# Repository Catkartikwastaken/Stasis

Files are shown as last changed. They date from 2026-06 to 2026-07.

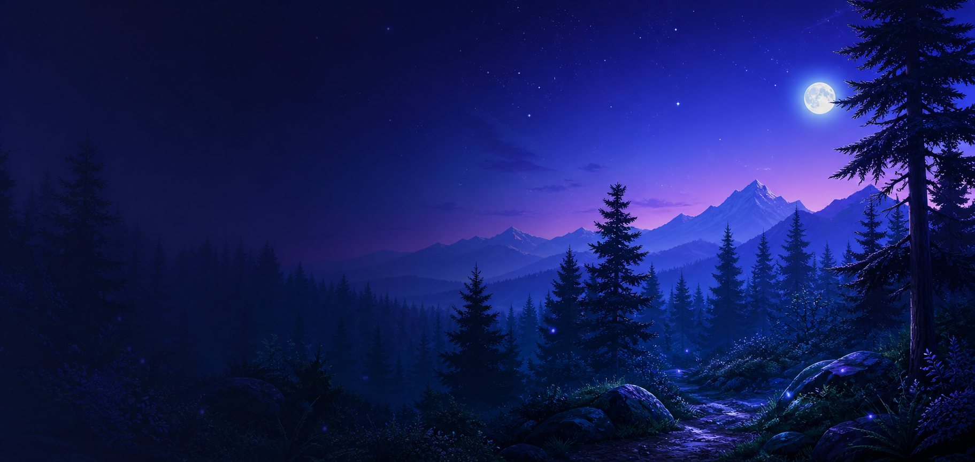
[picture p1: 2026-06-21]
docs/assets/forest-hero.jpg

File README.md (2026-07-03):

# STASIS

**A Raspberry Pi rover platform for forest-style monitoring, live camera streaming, object detection, and dashboard-guided response — built as a competition entry for field robotics and AI-integrated monitoring systems.**

STASIS is a competition-grade prototype for a small monitoring rover designed to showcase real-time edge-AI detection, telemetry-driven situational awareness, and operator-in-the-loop decision making. It is built around a Raspberry Pi 2B, a USB webcam, a Windows laptop for heavier vision processing, and a browser dashboard that shows what the rover sees and how it is responding.

The current build is focused on an indoor forest-like demo space: no GPS, no complicated field infrastructure, and no unnecessary hardware. The rover streams camera frames from the Raspberry Pi, the Windows server analyzes them, and the dashboard turns detections into clear alerts, map points, and simple movement guidance.

> **Competition Project Website:** [catkartikwastaken.github.io/Stasis](https://catkartikwastaken.github.io/Stasis)

## Highlights

| Area | What STASIS Does |
| --- | --- |
| Live rover vision | Streams the Raspberry Pi webcam feed to the dashboard. |
| Human detection | Detects people and surfaces them as high-priority dashboard alerts. |
| Object and marker detection | Supports demo objects, green-strip navigation markers, and empty-background dataset collection. |
| Rover control | Sends manual, scan, stop, return-home, and marker navigation commands from the dashboard to the Pi. |
| Minimal wiring | Keeps the main system centered on the Raspberry Pi, webcam, motor driver path, and optional ESP32-S3 bridge. |
| Extensible AI | Supports local or API-based vision providers, plus custom dataset capture for training a better model. |

## System Flow

The webcam belongs on the Raspberry Pi. The laptop runs the dashboard and the heavier AI work.

```mermaid
flowchart LR
    Camera["USB webcam on Raspberry Pi"] --> Pi["Raspberry Pi rover client"]
    Pi -->|"camera frames + telemetry"| Server["Windows STASIS server"]
    Server -->|"detections + commands"| Pi
    Server --> Dashboard["Browser dashboard"]
    Dashboard -->|"manual controls + tracking"| Server
    Pi --> Motors["L911S motors / optional ESP32-S3 bridge"]
```

In plain English:

1. The Raspberry Pi captures webcam frames.
2. The Pi sends frames to the Windows server through WebSocket.
3. The server runs the selected vision pipeline.
4. The result goes back to the Pi and appears on the dashboard.
5. The dashboard can track a detected target, show map dots, and send rover commands.

## Raspberry Pi Pin Map

Use BCM GPIO numbers in code. All pins are from the Raspberry Pi 2B 40-pin header.

| Function | BCM GPIO | Physical Pin |
| --- | --- | --- |
| Left motor forward | GPIO5 | Pin 29 |
| Left motor reverse | GPIO6 | Pin 31 |
| Right motor forward | GPIO13 | Pin 33 |
| Right motor reverse | GPIO19 | Pin 35 |
| Ultrasonic trigger | GPIO23 | Pin 16 |
| Ultrasonic echo | GPIO24 | Pin 18 |
| Scanner servo signal | GPIO18 | Pin 12 |
| I2C SDA | GPIO2 | Pin 3 |
| I2C SCL | GPIO3 | Pin 5 |
| 3.3V sensor power | 3V3 | Pin 1 or 17 |
| 5V power | 5V | Pin 2 or 4 |
| Ground | GND | Pin 6, 9, 14, 20, 25, 30, 34, or 39 |

## Hardware Connections

### Minimal Demo Wiring (Simplest Working Rover)

| Raspberry Pi | Component |
| --- | --- |
| USB port | USB webcam |
| GPIO5 | L911S A-IA (left motor forward) |
| GPIO6 | L911S A-IB (left motor reverse) |
| GPIO13 | L911S B-IA (right motor forward) |
| GPIO19 | L911S B-IB (right motor reverse) |
| GND | L911S GND |

**Motor power (separate battery):**
- Motor battery positive → L911S VCC / VM
- Motor battery negative → L911S GND (shared with Pi GND)
- L911S Motor A output → Left DC motor
- L911S Motor B output → Right DC motor

### L911S Direct Motor Control

| L911S Pin | Connect To |
| --- | --- |
| A-IA | Pi GPIO5 (pin 29) |
| A-IB | Pi GPIO6 (pin 31) |
| B-IA | Pi GPIO13 (pin 33) |
| B-IB | Pi GPIO19 (pin 35) |
| VCC / VM | Motor battery positive |
| GND | Motor battery negative + Pi GND |
| Motor A output | Left DC motor |
| Motor B output | Right DC motor |

Config: `"direct_motor_control": true`, `"esp32_serial_control": false`

### ESP32-S3 Optional Motor Bridge

Use only if you want serial-delegated motor control. Do NOT connect both Pi GPIO and ESP32 GPIO to the L911S simultaneously.

| Raspberry Pi | ESP32-S3 |
| --- | --- |
| USB port | ESP32-S3 USB/UART port |

| ESP32-S3 GPIO | L911S Pin |
| --- | --- |
| GPIO4 | A-IA |
| GPIO5 | A-IB |
| GPIO6 | B-IA |
| GPIO7 | B-IB |
| GND | L911S GND |

Config: `"direct_motor_control": false`, `"esp32_serial_control": true`, `"esp32_serial_port": "/dev/ttyUSB0"`, `"esp32_baudrate": 115200`

### USB Webcam

| Webcam | Raspberry Pi |
| --- | --- |
| USB cable | Pi USB port |

Verify: `ls /dev/video*`. Config: `"camera": { "enabled": true, "index": 0 }`

### HC-SR04 Ultrasonic Sensor

| HC-SR04 Pin | Connect To |
| --- | --- |
| VCC | 5V |
| GND | Pi GND |
| TRIG | GPIO23 (pin 16) |
| ECHO | GPIO24 (pin 18) **through voltage divider / level shifter (5V → 3.3V)** |

Config: `"ultrasonic_enabled": true`

### SG90 Scanner Servo

| Servo Wire | Connect To |
| --- | --- |
| Signal | GPIO18 (pin 12) |
| VCC | External 5V servo supply (not Pi 5V) |
| GND | External supply GND + Pi GND |

Config: `"scanner_servo_enabled": true`

### MPU6050 IMU (I2C)

| MPU6050 Pin | Connect To |
| --- | --- |
| VCC | 3.3V |
| GND | Pi GND |
| SDA | GPIO2 (pin 3) |
| SCL | GPIO3 (pin 5) |

Config: `"i2c_enabled": true`, `"mpu6050_enabled": true`

### HMC5883L / QMC5883L Compass (I2C)

| Compass Pin | Connect To |
| --- | --- |
| VCC | 3.3V |
| GND | Pi GND |
| SDA | GPIO2 (pin 3) |
| SCL | GPIO3 (pin 5) |

Config: `"i2c_enabled": true`, `"compass_enabled": true`

### Important Power Rules

1. Do **not** power DC motors from Raspberry Pi 5V.
2. Use a separate motor battery for the L911S motor driver.
3. Pi GND, L911S GND, sensor GND, servo GND, and motor battery negative must share common ground.
4. Pi GPIO pins are 3.3V logic. HC-SR04 Echo is 5V — use a voltage divider/level shifter.
5. Do not power a moving servo from Pi 5V if it causes resets.

### Fault-Tolerant Behavior

Missing sensors are logged as warnings and disabled; the rest of the system keeps running. Camera streaming and object detection work even when motors, IMU, compass, or ultrasonic are disconnected.

## What It Detects

STASIS keeps detections focused on the rover mission:

```text
human              people or intruders in the demo area
animal             animal stand-ins or wildlife-style targets
alpha_tester_object custom demo objects for the trained dataset
green_strip          navigation marker strips
empty_background   clean negative examples for model training
fire / track       supported in the broader alert contract
```

For the current demo, normal indoor doors, windows, and random room features should not become target alerts.

## Quick Start

### 1. Start The Windows Server

On the Windows laptop:

```powershell
cd server
py -m venv .venv
.\.venv\Scripts\activate
python -m pip install --upgrade pip
pip install -r requirements-api.txt
copy vision_config.example.json vision_config.json
python security_rover_server_windows.py
```

The server prints an address such as:

```text
http://192.168.29.69:5000
```

Use that IP in the Raspberry Pi config.

### 2. Start The Raspberry Pi Rover

On the Raspberry Pi:

```bash
cd ~/Documents/Stasis/rover/rpi2b
python3 -m venv .venv
. .venv/bin/activate
python -m pip install --upgrade pip
pip install -r requirements.txt
cp config.example.json config.json
nano config.json
```

Set `server_host` to the Windows laptop IP:

```json
{
  "server_host": "192.168.29.69"
}
```

Then run the rover client:

```bash
python rover_client.py --config config.json
```

Use `--simulate` only for network testing. For the real rover, keep simulation off.

### 3. Open The Dashboard

On the laptop browser:

```text
http://<WINDOWS_LAPTOP_IP>:5000
```

You should see the live Pi webcam feed, rover status, controls, alerts, and the tracking map.

## Dataset Capture

STASIS includes a beginner-friendly webcam capture tool for building a custom object dataset:

```powershell
python tools\dataset_capture_assistant.py
```

It captures:

- `alpha_tester_object`
- `green_strip`
- `empty_background`

The tool lets you choose camera resolution, FPS, brightness, contrast, exposure, focus, and save location from the app itself. See [Dataset Capture Assistant](docs/DATASET_CAPTURE_ASSISTANT.md).

## Competition Project Website

The project's competition landing page is live at **[catkartikwastaken.github.io/Stasis](https://catkartikwastaken.github.io/Stasis)**.

The site (built from [docs/index.html](docs/index.html)) covers the system overview, rover pipeline, scroll-driven mission reel, setup instructions, hardware connections, and links to all project documentation — presented as a polished field platform showcase.

## Project Structure

```text
server/
  templates/index.html                    Main dashboard UI
  vision_config.example.json              Vision provider configuration template

rover/rpi2b/
  rover_client.py                         Raspberry Pi rover client
  rover_client_object_detection.py        Pi-side camera streaming and local detection path
  config.example.json                     Pi configuration template
  requirements.txt                        Pi dependencies

tools/
  dataset_capture_assistant.py            Webcam dataset collection app

hardware/cad/stasis-design/
  stasis-redesigns-compartment.zip        Archive containing redesign and compartment CAD assets

docs/
  index.html                              GitHub Pages project website
  README_ROVER_SYSTEM.md                  Full rover setup guide
  VISION_PROVIDERS.md                     Cloud/local AI provider notes
  WINDOWS_YOLO_ONNX_DETECTION.md          Windows ONNX detector guide
  DATASET_CAPTURE_ASSISTANT.md            Dataset tool guide
```

## Documentation

- [Full Rover System Guide](docs/README_ROVER_SYSTEM.md)
- [Wiring And Runbook](docs/WIRING_AND_RUNBOOK.md)
- [Vision Providers](docs/VISION_PROVIDERS.md)
- [Windows YOLO ONNX Detection](docs/WINDOWS_YOLO_ONNX_DETECTION.md)
- [Dataset Capture Assistant](docs/DATASET_CAPTURE_ASSISTANT.md)
- [Project Brief](docs/PROJECT_BRIEF.md)

## Current Limits

STASIS is still a prototype, so the current build is intentionally honest about what it can and cannot do:

- GPS is not used for the indoor demo.
- Distance and map guidance are approximate without wheel encoders.
- Heavy AI should run on the laptop or through an API, not on the Raspberry Pi 2B.
- Custom object detection quality depends heavily on the dataset and trained model.
- Optional sensors should stay disabled until the hardware is physically connected.

## License

This project is intended as an open-source learning and robotics build. Add the final license file before using it in a public release or competition submission.

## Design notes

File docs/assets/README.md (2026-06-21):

# STASIS Pages Assets

Website images:

- `forest-hero.jpg` - original generated forest hero image
- `stasis-forest-real.jpg` - realistic field background for the current home page

The GitHub Pages site at `docs/index.html` is already wired to use these local files.

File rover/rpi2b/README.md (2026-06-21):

# STASIS Raspberry Pi 2B Rover Client

This Python client runs the Raspberry Pi 2B side of the STASIS rover. It connects to the existing STASIS Flask server at `ws://<SERVER_IP>:5000/ws/rover`, registers as `rpi2b_rover`, accepts `goto`, `scan`, and `stop` commands, drives the L911S/L9110S motor driver, reads optional MPU6050 and GY-271/HMC5883L sensors, scans with optional HC-SR04 and servo hardware, and sends telemetry back to the dashboard.

The USB webcam connects to the Raspberry Pi. The Pi captures frames with Python/OpenCV, sends them to the Windows laptop over the rover WebSocket, receives Gemma `vision_result` messages, and sends `vision_decision` back to the server/dashboard.

The default config is intentionally minimal-wire: the Pi drives motors directly, but I2C heading sensors, ultrasonic, and the scanner servo are disabled until you enable them. With no heading sensor, the client uses timed open-loop turns for the indoor demo.

## Raspberry Pi Setup

Use Raspberry Pi OS on the Pi 2B and enable I2C:

```bash
sudo raspi-config
```

Open `Interface Options`, enable `I2C`, then reboot.

Install dependencies:

```bash
cd rover/rpi2b
python3 -m venv .venv
. .venv/bin/activate
python -m pip install --upgrade pip
pip install -r requirements.txt
```

Create a local config:

```bash
cp config.example.json config.json
```

Edit `server_host` to the IP address of the laptop running `server/security_rover_server_windows.py` or `server/security_rover_server.py`.

Keep the webcam section enabled for the real demo:

```json
{
  "camera": {
    "enabled": true,
    "index": 0,
    "width": 640,
    "height": 480,
    "upload_interval_seconds": 2.0
  }
}
```

If the Pi opens the wrong webcam, change `camera.index` to `1` or `2`.

Enable optional hardware and ESP32 serial motor control only when they are physically connected:

```json
{
  "hardware": {
    "direct_motor_control": false,
    "esp32_serial_control": true,
    "esp32_serial_port": "/dev/ttyUSB0",
    "esp32_baudrate": 115200,
    "i2c_enabled": true,
    "mpu6050_enabled": true,
    "compass_enabled": true,
    "ultrasonic_enabled": true,
    "scanner_servo_enabled": true
  }
}
```

Hardware is initialized per subsystem. A missing ultrasonic sensor, scanner servo, MPU6050, compass, or motor driver is logged and disabled without stopping the rest of the Pi client, so camera streaming and object detection can keep running.

Run the rover:

```bash
python rover_client.py --config config.json
```

For a laptop protocol test without GPIO hardware:

```bash
python rover_client.py --server 192.168.1.10 --simulate
```

To run the client automatically on boot, edit `stasis-rover.service.example` so the paths match where this repo lives on your Pi, copy it to `/etc/systemd/system/stasis-rover.service`, then run:

```bash
sudo systemctl daemon-reload
sudo systemctl enable --now stasis-rover
sudo systemctl status stasis-rover
```

## Wiring Diagrams

The rover supports direct GPIO motor control and optional mediated ESP32-S3 control. Direct GPIO can use either `l911s` or `l298n` mode.

The physical rover uses four DC motors. The software still drives it as a differential rover with two side channels: the two left motors receive the same left-side signal, and the two right motors receive the same right-side signal. Wire both left motors to the left motor channel and both right motors to the right motor channel only if your motor driver and battery can safely supply the total current.

### Option A: Direct Raspberry Pi GPIO L911S Control
Uses Raspberry Pi BCM GPIO pin allocations:

```text
BCM 5   -> A-IA / IA, left motor forward input
BCM 6   -> A-IB / IB, left motor reverse input
BCM 13  -> B-IA, right motor forward input
BCM 19  -> B-IB, right motor reverse input
GND     -> L911S/L9110S GND and motor battery negative
VM/VCC  -> Motor battery positive, matched to your motors/driver board
Motor A output -> both left-side DC motors
Motor B output -> both right-side DC motors
```

### Option B: Direct Raspberry Pi GPIO L298N Control
Use this if the L911S channel is damaged or if you want a stronger dual H-bridge module:

```text
BCM 5   -> IN1, left motor forward input
BCM 6   -> IN2, left motor reverse input
BCM 13  -> IN3, right motor forward input
BCM 19  -> IN4, right motor reverse input
BCM 12  -> ENA, left speed enable
BCM 20  -> ENB, right speed enable
GND     -> L298N GND and motor battery negative
+V      -> Motor battery positive, matched to your motors
OUT1/2  -> left-side DC motor or motor pair
OUT3/4  -> right-side DC motor or motor pair
```

Config:

```json
"hardware": {
  "direct_motor_control": true,
  "motor_driver": "l298n"
},
"pins": {
  "left_motor_forward": 5,
  "left_motor_reverse": 6,
  "right_motor_forward": 13,
  "right_motor_reverse": 19,
  "left_motor_enable": 12,
  "right_motor_enable": 20
}
```

Remove the ENA/ENB jumpers for Raspberry Pi speed control. If the jumpers stay installed, set `left_motor_enable` and `right_motor_enable` to `null`.

### Option C: ESP32-S3 Mediated L911S Control
Raspberry Pi communicates with the ESP32-S3 via USB-Serial. The ESP32-S3 drives the H-bridge directly:

**1. USB Link:**
- USB port of the Raspberry Pi 2B connected via USB cable to the ESP32-S3's UART/USB port.

**2. ESP32-S3 to L911S Wiring:**
```text
ESP32 Pin 4 (GPIO4) -> A-IA, left motor forward input
ESP32 Pin 5 (GPIO5) -> A-IB, left motor reverse input
ESP32 Pin 6 (GPIO6) -> B-IA, right motor forward input
ESP32 Pin 7 (GPIO7) -> B-IB, right motor reverse input
GND                 -> L911S GND and motor battery negative
VM/VCC              -> Motor battery positive
Motor A output      -> both left-side DC motors
Motor B output      -> both right-side DC motors
```

---

### Onboard I2C Sensors & Sonar Sweep Peripherals

I2C sensors:

```text
BCM 2 / physical pin 3  -> SDA
BCM 3 / physical pin 5  -> SCL
3V3                     -> MPU6050 VCC and GY-271 VCC
GND                     -> MPU6050 GND and GY-271 GND
MPU6050 address         -> 0x68
GY-271/HMC5883L address -> 0x1E
```

HC-SR04 ultrasonic sensor:

```text
BCM 23 -> Trig
BCM 24 -> Echo
5V or 3V3 -> VCC
GND -> GND
```

Raspberry Pi GPIO is not 5V tolerant. If the HC-SR04 is powered from 5V, put a voltage divider or level shifter on Echo before it reaches BCM 24.

Scanner servo:

```text
BCM 18 -> Signal
5V     -> Servo power
GND    -> Ground
```

Use a common ground between the Pi, motor driver, motor battery, sensors, and servo. Use a separate motor/servo supply where possible because motor noise and voltage dips can reboot the Pi.

## Tuning

Open-loop distance and minimal-wire turning are approximate because the rover has no wheel encoders. Tune these values in `config.json`:

```json
{
  "hardware": {
    "open_loop_turn_degrees_per_second": 90.0
  },
  "motion": {
    "drive_ms_per_cm": 50.0,
    "drive_pwm": 70.0,
    "turn_kp": 0.8,
    "turn_tolerance_deg": 5.0
  }
}
```

If the rover drives too far, lower `drive_ms_per_cm`. If it stops short, raise it. If turning oscillates, lower `turn_kp`; if it turns too slowly, raise `turn_kp` or `turn_min_pwm`.

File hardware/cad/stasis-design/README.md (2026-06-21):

# STASIS CAD Archive

This folder now keeps a single archive:

```text
stasis-redesigns-compartment.zip
```

The zip contains the redesign and compartment CAD assets exported from:

```text
C:\Users\CatKartikSUPREMEPC\Documents\Stasis Design
```

It replaces the extracted file tree so the repo stays compact while still carrying the design package.

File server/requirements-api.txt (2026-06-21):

flask
flask-socketio
simple-websocket
opencv-python
numpy
pillow
requests

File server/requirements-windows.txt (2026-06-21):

flask
flask-socketio
simple-websocket
opencv-python
pillow
requests
torch
torchvision
transformers>=4.53.0
accelerate
sentencepiece
protobuf

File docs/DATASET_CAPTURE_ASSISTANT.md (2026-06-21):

---
title: Dataset Capture Assistant
---

# Dataset Capture Assistant

Use this tool to take training photos with the webcam in a simple manual workflow. It opens a persistent desktop app, shows what kind of scene to capture next, and saves photos without closing the app.

## Install

From the repo root:

```powershell
python -m pip install opencv-python numpy pillow
```

## Start

```powershell
python tools\dataset_capture_assistant.py
```

Pick the class from the dropdown, then follow the on-screen prompts.

You can also start a class directly:

```powershell
python tools\dataset_capture_assistant.py --class-name green_strip
python tools\dataset_capture_assistant.py --class-name alpha_tester_object
python tools\dataset_capture_assistant.py --class-name empty_background
```

Images are saved to:

```text
C:\Users\<you>\Pictures\STASIS_Dataset\raw\<class_name>\
```

Use the `Choose Folder` button if you want another save location.

## Controls

```text
Space/C = capture now
N = next idea
L = next location
R = delete last saved image
Q = quit
```

## Camera Settings

The app lets you change common webcam settings without editing code:

```text
camera index
width
height
FPS
brightness
contrast
exposure
focus
```

The camera/settings sidebar is scrollable. Use the mouse wheel if the lower settings are outside the window.

It also shows:

```text
current resolution
estimated megapixels
camera backend
current property values
```

Most webcams do not report live electrical power usage through normal camera drivers, so the app shows power draw as unavailable when the camera does not expose it.

## Recommended Use

For the current demo dataset, use:

```text
alpha_tester_object
green_strip
empty_background
```

Take roughly 200 total photos across 4 locations. Mix objects together naturally, but still take empty background photos so the model learns when nothing important is present.

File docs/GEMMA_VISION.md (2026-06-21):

---
title: Gemma Vision
---

# Gemma Vision Integration

STASIS uses Gemma on the Windows laptop/server to inspect USB webcam frames captured by the Raspberry Pi. The rover does not run Gemma; the Raspberry Pi 2B captures the webcam, streams frames to Windows, receives `vision_result`, decides the action, and sends `vision_decision` back to the dashboard/server.

Gemma is now one supported local provider, not the only vision option. For Gemini API, OpenAI, Anthropic, Qwen DashScope, Kimi, Zhipu, Ollama, or LM Studio, use `docs/VISION_PROVIDERS.md`.

## Default Model

The server defaults to:

```text
google/gemma-4-E2B-it
```

This is a multimodal Gemma instruct model that supports image + text input through Hugging Face Transformers. The server uses the documented `any-to-any` pipeline and sends a chat-style message containing:

```text
1. The latest Raspberry Pi webcam frame as a PIL image.
2. A strict JSON instruction prompt.
```

The expected model response is:

```json
{"detected": true, "category": "human", "message": "person visible beside the patrol marker"}
```

or:

```json
{"detected": false, "category": "", "message": ""}
```

The server calls the pipeline with `return_full_text=False` and deterministic generation settings so the parser sees only Gemma's new answer, not the original prompt.

## Hugging Face Access

Gemma 4 model weights are hosted on Hugging Face. If your environment needs authentication for downloads or you hit rate limits, create a Hugging Face access token.

Set the token before starting the server.

PowerShell:

```powershell
$env:HF_TOKEN = "hf_your_token_here"
```

Bash:

```bash
export HF_TOKEN="hf_your_token_here"
```

You can also run `huggingface-cli login` on the server machine.

## Install

Install the normal server requirements. They include the Transformers version needed for Gemma any-to-any inference.

Windows PowerShell:

```powershell
cd server
py -m venv .venv
.\.venv\Scripts\activate
python -m pip install --upgrade pip
pip install -r requirements-windows.txt
```

Linux:

```bash
cd server
python3 -m venv .venv
. .venv/bin/activate
python -m pip install --upgrade pip
pip install -r requirements.txt
```

If you are using only API providers, Ollama, or LM Studio, install `requirements-api.txt` instead. That lighter install does not require Torch.

## Configuration

For local Gemma, copy `server/vision_config.example.json` to `server/vision_config.json`, enable `local_gemma`, and put it in `provider_order`. The legacy environment variables below still work for Gemma tuning when needed:

```text
STASIS_VISION_ENABLED=true
STASIS_VISION_REQUIRED=false
STASIS_VISION_MODEL=google/gemma-4-E2B-it
STASIS_VISION_PIPELINE_TASK=any-to-any
STASIS_VISION_DEVICE=auto
STASIS_VISION_DEVICE_MAP=none
STASIS_VISION_TORCH_DTYPE=auto
STASIS_VISION_MAX_NEW_TOKENS=160
STASIS_ANALYSIS_INTERVAL_SECONDS=2
STASIS_CAMERA_SOURCE=rover
STASIS_CAMERA_INDEX=0
STASIS_CAMERA_WIDTH=640
STASIS_CAMERA_HEIGHT=480
STASIS_CAMERA_FPS=15
STASIS_CAMERA_BACKEND=dshow
```

Recommended Windows CUDA settings:

```powershell
$env:STASIS_VISION_DEVICE = "cuda"
$env:STASIS_VISION_DEVICE_MAP = "none"
$env:STASIS_VISION_TORCH_DTYPE = "bfloat16"
$env:STASIS_VISION_REQUIRED = "true"
python security_rover_server_windows.py
```

CPU fallback:

```powershell
$env:STASIS_VISION_DEVICE = "cpu"
$env:STASIS_VISION_DEVICE_MAP = "none"
$env:STASIS_VISION_TORCH_DTYPE = "float32"
python security_rover_server_windows.py
```

CPU inference can be slow. If you only want to test rover control and the dashboard, disable vision:

```powershell
$env:STASIS_VISION_ENABLED = "false"
python security_rover_server_windows.py
```

## Prompt Contract

The server prompt asks Gemma to return only one JSON object:

```json
{"detected": boolean, "category": "human|animal|track|fire|marker", "message": string}
```

The parser accepts plain JSON or the first valid JSON object embedded in extra model text. If `detected` is false, the server clears `message` before broadcasting. If the category is missing or outside the STASIS categories, the alert is suppressed. If the response cannot be parsed, the error is logged and no alert is emitted for that frame.

The default categories for the forest-monitoring demo are:

```text
human   -> humans, intruders, people in the test area
animal  -> animals or wildlife stand-ins
track   -> footprints, trails, soil changes, disturbed ground, track marks
fire    -> flame, smoke, fire-like hazards
marker  -> custom navigation markers such as green strips
```

The demo is indoors, but the prompt treats the scene as a staged forest floor. It intentionally avoids alerting on ordinary doors or windows unless they matter to the demo setup.

To customize the prompt:

PowerShell:

```powershell
$env:STASIS_ANALYSIS_PROMPT = "Analyze this STASIS forest-monitoring rover frame for humans, animals, tracks, fire, or red navigation strips. Return only JSON with detected and message."
```

Keep the same JSON schema so the dashboard and category filter continue to work.

## Troubleshooting

If model loading fails with an authorization error:

```text
1. Set HF_TOKEN or run huggingface-cli login.
2. Restart the server.
```

If model loading fails because of Transformers support:

```bash
pip install --upgrade "transformers>=4.53.0" torch torchvision accelerate sentencepiece protobuf
```

If CUDA runs out of memory:

```text
1. Lower STASIS_CAMERA_WIDTH and STASIS_CAMERA_HEIGHT.
2. Increase STASIS_ANALYSIS_INTERVAL_SECONDS.
3. Try STASIS_VISION_TORCH_DTYPE=bfloat16.
4. Disable vision while testing rover control.
```

If the wrong webcam opens on the Raspberry Pi, change `camera.index` in `rover/rpi2b/config.json`, then restart the Pi rover client. If you intentionally test with a laptop webcam, set `STASIS_CAMERA_SOURCE=local` on Windows and then use `STASIS_CAMERA_INDEX`.

If alerts are noisy, adjust `STASIS_ANALYSIS_PROMPT` to describe only the objects or events that matter for your test space.

## References

- Hugging Face model page: https://huggingface.co/google/gemma-4-E2B-it
- Google Gemma documentation: https://ai.google.dev/gemma

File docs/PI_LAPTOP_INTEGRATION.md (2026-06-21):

# STASIS Pi ↔ Laptop Integration (Stable Path)

This mode runs object detection on the **Windows laptop** while the **Pi only streams camera + telemetry**.

## 1) Windows laptop (server + detector)

From PowerShell:

```powershell
cd C:\Users\Car\Documents\Stasis\server
python -m pip install -r requirements-object-detection.txt

$env:STASIS_DETECTION_AUTHORITY="windows"
$env:STASIS_WINDOWS_DETECTOR_RUNTIME="ultralytics"
$env:STASIS_ULTRALYTICS_MODEL="yoloe-26s-seg.pt"
$env:STASIS_ULTRALYTICS_DEVICE="cuda:0"
$env:STASIS_REQUIRE_CUDA="false"
$env:STASIS_OBJECT_ANALYSIS_INTERVAL_SECONDS="0.2"

python security_rover_server_object_detection.py
```

Notes:
- If CUDA is unavailable and `STASIS_REQUIRE_CUDA=false`, server falls back to CPU.
- Dashboard URL: `http://127.0.0.1:5000`

## 2) Raspberry Pi (stream camera + rover control)

Use the profile `rover/rpi2b/profiles/laptop_detection_pi_stream.json`.

- This profile is stream-only (no Pi-side detector block).
- Set `server_host` in the profile to your laptop IP, or override via env:
  `export STASIS_SERVER_HOST=<LAPTOP_IP>`

Then run:

```bash
cd ~/Documents/Stasis/rover/rpi2b
source .venv/bin/activate
python rover_client.py --config profiles/laptop_detection_pi_stream.json
```

## 3) Validation checklist

- Pi logs show successful WebSocket handshake/registration.
- Laptop logs show: `Windows-side detection active with 1 detector(s).`
- Laptop logs show repeated detection debug entries after Pi frames arrive.
- Dashboard (`/`) shows live camera feed and detection overlays/debug rows.

## 4) Troubleshooting

- If camera feed is blank: verify Pi `server_host`, websocket path `/ws/rover`, and webcam index on Pi.
- If detections are missing: set `STASIS_ULTRALYTICS_MODEL="yolo11n.pt"` to sanity-check baseline detection.
- If too slow: lower `STASIS_ULTRALYTICS_IMGSZ` (for example `512`).

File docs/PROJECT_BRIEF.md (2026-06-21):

---
title: Project Brief
---

# STASIS Project Brief

STASIS is a forest monitoring rover. The first demo will happen indoors in a forest-like test space, so the system should behave like a patrol robot without depending on GPS.

## Current Mission

The rover should patrol a test area, watch the camera feed, and notify the dashboard when the selected multimodal model sees something important.

Primary detection targets:

```text
Humans/intruders
Animals or wildlife stand-ins
Soil changes, tracks, footprints, trails, or disturbed ground
Fire, smoke, or flame-like hazards
Custom colored markers or strips, especially green strips
```

Intruders are classified under the `human` category. Ordinary indoor doors and windows are not target classes for this project.

## Demo Hardware Plan

Current hardware assumptions:

```text
Laptop              -> Flask/Socket.IO server, dashboard, multimodal AI provider
USB webcam          -> Camera input captured by Raspberry Pi Python/OpenCV
Raspberry Pi 2B     -> High-level rover client, camera streaming, logic, state, and telemetry
ESP32-S3 (Optional) -> Low-level serial motor driver (serial control mode)
L911S motor driver  -> A-IA/A-IB and B-IA/B-IB motor inputs (driven by ESP32 or direct Pi)
Sensors             -> Obstacle avoidance, heading, scan, and demo telemetry
```

The old embedded camera path has been completely removed. The Raspberry Pi now captures the USB webcam, streams JPEG frames to the Windows laptop for multimodal AI processing, receives the vision result, and decides whether to stop, alert, remember a marker, or continue. The dashboard camera feed is served from the latest Pi frame at `/camera.mjpg`. The ESP32-S3 code is dedicated strictly to low-level motor driver controls, serving as a serial-to-PWM bridge for the L911S to ensure stable and highly precise timing.

The current code supports two motor driver topologies: Option A (Direct Raspberry Pi BCM GPIO control) and Option B (ESP32-S3 USB/UART serial delegated control). The default configuration can be run in minimal-wire direct mode or serial-delegated mode; optional I2C heading sensors, ultrasonic, and servo scanning are disabled by default until explicitly enabled in the configuration file.

## Behavior Targets

STASIS should support:

```text
Autonomous patrol scripts
Manual dashboard controls
Clicked map goals
Return-to-home
Obstacle avoidance
Human/intruder alerts
Animal alerts
Track and soil-change alerts
Fire alerts
Custom marker search and marker-directed patrol
```

For the green-strip demo, the rover should be able to scan for a requested strip, remember where it was found, and later drive back to that strip when commanded.

The Pi now receives vision results before an alert is shown. For humans and fire it stops and approves an alert; for markers it approves the marker memory path so the dashboard can request a green-strip search and command the rover back to the last seen strip.

## Open Decisions

These details should be confirmed before the next hardware-specific implementation pass:

```text
Exact sensor list and which board each sensor connects to
Marker colors, marker names, and what action each marker should trigger
Indoor demo arena size and expected patrol route shape
```

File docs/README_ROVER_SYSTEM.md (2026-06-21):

---
title: Rover System
---

# STASIS Forest Monitoring Rover System

## Plain-English Overview

STASIS has two main computers:

```text
Raspberry Pi 2B  -> sits on the rover, uses the webcam, controls movement
Windows laptop   -> runs the dashboard and selected multimodal vision provider
```

The Raspberry Pi is the rover brain. It captures webcam frames, sends them to the Windows laptop, receives the AI vision result, and decides what the rover should do next.

The Windows laptop is the AI and dashboard station. It calls the configured multimodal provider, serves the web dashboard, and passes commands between the dashboard and the Pi.

The webcam should be connected to the Raspberry Pi for the real demo. The laptop webcam mode exists only for quick testing.

This repository contains a complete starter setup for STASIS, a forest monitoring rover that will be demonstrated indoors in a forest-like environment:

1. A USB webcam connects to the Raspberry Pi.
2. The Raspberry Pi 2B runs the Python rover client, captures webcam frames, and controls the rover.
3. A laptop runs the Flask/Socket.IO vision and command server.
4. A browser dashboard sends map goals and displays alerts.

The Raspberry Pi client is the active high-level rover controller in this branch. Old embedded camera code has been fully removed from the ESP32-S3, and its firmware now serves exclusively as a low-level USB-to-Serial motor control delegator (serial-to-PWM bridge) for the L911S driver. This ensures precise PWM motor drive signals and offloads low-level timing tasks from the Raspberry Pi.

The demo does not depend on GPS. Navigation stays local: manual dashboard driving, clicked goals, return-to-home, obstacle avoidance, scan commands, and marker-directed patrols.

## File Locations

```text
rover/esp32_s3/stasis_motor_controller.ino
rover/rpi2b/rover_client.py
rover/rpi2b/config.example.json
rover/rpi2b/requirements.txt
rover/rpi2b/README.md
rover/rpi2b/stasis-rover.service.example
server/security_rover_server.py
server/security_rover_server_windows.py
server/vision_config.example.json
server/requirements.txt
server/requirements-windows.txt
server/requirements-api.txt
server/templates/index.html
dashboard/rover_dashboard.html
dashboard/rover_dashboard_windows.html
docs/GEMMA_VISION.md
docs/VISION_PROVIDERS.md
docs/README_ROVER_SYSTEM.md
```

## How The Pieces Work Together

The Raspberry Pi captures the USB webcam with OpenCV and sends JPEG frames to the laptop over the rover WebSocket. The laptop serves the latest rover camera frame here:

```text
http://<SERVER_IP>:5000/camera.mjpg
```

The Raspberry Pi rover connects to the laptop at:

```text
ws://<SERVER_IP>:5000/ws/rover
```

After connecting, the Pi sends:

```json
{"id":"rpi2b_rover","type":"rover"}
```

The dashboard connects by Socket.IO to:

```text
http://<SERVER_IP>:5000
```

When the dashboard sends `set_goal`, the server converts the clicked map point into a rover command:

```json
{"cmd":"goto","angle":45.2,"distance":30.5}
```

When the rover finishes, it sends:

```json
{"status":"goal_reached"}
```

When the selected multimodal provider detects a relevant forest-monitoring event, the laptop sends a `vision_result` back to the Raspberry Pi. The Pi decides the action, for example `stop_and_alert` for humans or fire, then returns `vision_decision`. The server uses that Pi decision to emit `new_alert` to the dashboard. Target events include humans/intruders, animals, visible track or soil changes, fire/smoke/flame, and custom colored markers such as green strips. API, Ollama, LM Studio, and local Gemma setup details live in `docs/VISION_PROVIDERS.md`.

The server accepts alerts only for these categories:

```text
human
animal
track
fire
marker
```

If the selected model returns a category outside that list, the server suppresses the alert.

## Raspberry Pi 2B Rover Responsibilities

The Python client handles the major rover-control functions on the Raspberry Pi:

```text
Wi-Fi/server setup       -> config.json, CLI flags, or STASIS_SERVER_HOST
WebSocket registration   -> websocket-client
Motor control (Option A) -> RPi.GPIO PWM direct connection to L911S
Motor control (Option B) -> SerialMotorDriver delegator over USB-serial to ESP32-S3
MPU6050 gyro yaw         -> smbus2 I2C
GY-271 compass heading   -> smbus2 I2C
HC-SR04 scan distance    -> RPi.GPIO timing
Scanner servo sweep      -> RPi.GPIO PWM
Telemetry heartbeat      -> JSON over WebSocket
Goto and scan commands   -> Python command worker
```

The default Pi config starts in minimal-wire mode:

```text
Direct motor control: enabled (Option A) or delegated serial control (Option B)
I2C heading sensors: disabled
Ultrasonic sensor: disabled
Scanner servo: disabled
Goto turning: timed open-loop fallback
```

Enable optional sensors and configure the active motor driving mode in `rover/rpi2b/config.json` only after the hardware is physically connected.

## Rover Wiring Diagrams

The default pin numbers use BCM numbering. You can change these allocations in `rover/rpi2b/config.json`. The rover supports two motor driving topologies: direct Pi control and delegated ESP32-S3 control.

The physical rover uses four DC motors. The software drives two differential side channels: left side and right side. Wire both left motors to the left channel and both right motors to the right channel only if the motor driver board and motor battery can handle the combined current.

### Option A: Direct Raspberry Pi GPIO Motor Control
Direct connection to the L911S/L9110S motor driver from Raspberry Pi BCM GPIO pins:

```text
BCM 5   -> A-IA / IA, left motor forward input
BCM 6   -> A-IB / IB, left motor reverse input
BCM 13  -> B-IA, right motor forward input
BCM 19  -> B-IB, right motor reverse input
GND     -> L911S/L9110S GND and motor battery negative
VM/VCC  -> Motor battery positive, matched to your motors/driver board
Motor A -> both left-side motor terminals
Motor B -> both right-side motor terminals
```

Some L911S boards label the two channels as `A-IA`, `A-IB`, `B-IA`, and `B-IB`. Smaller boards may label a single channel as only `IA` and `IB`; use that pair for the left motor channel and the second pair for the right motor channel.

### Option B: ESP32-S3 Delegated Motor Control (Recommended)
The Raspberry Pi communicates with the ESP32-S3 over a USB/UART Serial connection. The ESP32-S3 then drives the L911S H-Bridge.

**1. Pi-to-ESP32 Connection:**
- USB Cable connecting a USB port on the Raspberry Pi directly to the ESP32-S3's USB/UART Port (mounts as `/dev/ttyUSB0` or `/dev/ttyACM0` on the Pi, or `COMx` on Windows).

**2. ESP32-S3 to L911S Driver Wiring:**
```text
ESP32 Pin 4 (GPIO4) -> A-IA, left motor forward input
ESP32 Pin 5 (GPIO5) -> A-IB, left motor reverse input
ESP32 Pin 6 (GPIO6) -> B-IA, right motor forward input
ESP32 Pin 7 (GPIO7) -> B-IB, right motor reverse input
GND                 -> L911S GND and motor battery negative
VM/VCC              -> Motor battery positive
Motor A             -> both left-side motor terminals
Motor B             -> both right-side motor terminals
```

---

### Onboard I2C Sensors & Sonar Sweep Peripherals

MPU6050 and GY-271/HMC5883L:

```text
BCM 2 / physical pin 3  -> SDA
BCM 3 / physical pin 5  -> SCL
3V3                     -> VCC
GND                     -> GND
MPU6050 address         -> 0x68
GY-271/HMC5883L address -> 0x1E
```

The MPU6050 and GY-271 share the same I2C bus.

HC-SR04 ultrasonic sensor:

```text
BCM 23 -> Trig
BCM 24 -> Echo
VCC    -> 5V or 3V3
GND    -> GND
```

Raspberry Pi GPIO is not 5V tolerant. If the HC-SR04 is powered from 5V, put a voltage divider or level shifter on Echo before it reaches BCM 24.

Scanner servo:

```text
BCM 18 -> Signal
5V     -> Power/red
GND    -> Ground/brown
```

Use a common ground between the Pi, ESP32-S3, motor driver, motor battery, sensors, and servo. Use a separate motor/servo supply when possible because motor noise and voltage dips can reboot the Pi.

## Raspberry Pi Setup

Enable I2C on the Pi:

```bash
sudo raspi-config
```

Open `Interface Options`, enable `I2C`, then reboot.

Install the rover client dependencies:

```bash
cd rover/rpi2b
python3 -m venv .venv
. .venv/bin/activate
python -m pip install --upgrade pip
pip install -r requirements.txt
cp config.example.json config.json
```

Edit `config.json`:

```json
{
  "server_host": "192.168.1.10",
  "rover_id": "rpi2b_rover",
  "hardware": {
    "direct_motor_control": false,
    "esp32_serial_control": true,
    "esp32_serial_port": "/dev/ttyUSB0",
    "esp32_baudrate": 115200,
    "i2c_enabled": false,
    "ultrasonic_enabled": false,
    "scanner_servo_enabled": false
  }
}
```

Run the rover:

```bash
python rover_client.py --config config.json
```

You can also pass the server directly:

```bash
python rover_client.py --server 192.168.1.10
```

For a protocol-only test without GPIO/I2C hardware:

```bash
python rover_client.py --server 192.168.1.10 --simulate
```

To start the rover client automatically on boot, edit `rover/rpi2b/stasis-rover.service.example` so its paths match the repo location on your Pi, copy it to `/etc/systemd/system/stasis-rover.service`, then run:

```bash
sudo systemctl daemon-reload
sudo systemctl enable --now stasis-rover
sudo systemctl status stasis-rover
```

## Windows Laptop Version

Use this server on Windows:

```text
server/security_rover_server_windows.py
```

It can use Moondream + a tiny text formatter through Ollama, cloud APIs, LM Studio, or local Gemma. API/Ollama/LM Studio mode does not need Torch.

Install dependencies from PowerShell:

```powershell
cd server
py -m venv .venv
.\.venv\Scripts\activate
python -m pip install --upgrade pip
pip install -r requirements-api.txt
copy vision_config.example.json vision_config.json
```

Edit `vision_config.json` and enable one provider. For the local competition setup, enable `moondream_stasis` and pull `moondream` plus `qwen2.5:0.5b` in Ollama. Provider setup details are in `docs/VISION_PROVIDERS.md`.

Only install the heavier local Gemma dependencies if you enable `local_gemma`:

```powershell
pip install -r requirements-windows.txt
```

Local Gemma alerts use `google/gemma-4-E2B-it` through Hugging Face Transformers. If your environment needs Hugging Face authentication for model downloads, set a token:

```powershell
$env:HF_TOKEN = "hf_your_token_here"
$env:STASIS_VISION_REQUIRED = "true"
```

Useful local Gemma settings:

```powershell
$env:STASIS_CAMERA_SOURCE = "rover"
$env:STASIS_VISION_DEVICE = "cuda"
$env:STASIS_VISION_DEVICE_MAP = "none"
$env:STASIS_VISION_TORCH_DTYPE = "bfloat16"
$env:STASIS_ANALYSIS_INTERVAL_SECONDS = "2"
```

To test rover control without loading vision:

```powershell
$env:STASIS_VISION_ENABLED = "false"
```

If you are testing with a laptop webcam instead of the Pi webcam, set `STASIS_CAMERA_SOURCE=local`, then use `STASIS_CAMERA_INDEX=1` or `2` if the wrong laptop camera opens.

Run:

```powershell
python security_rover_server_windows.py
```

Open:

```text
http://<WINDOWS_LAPTOP_IP>:5000
```

If Windows asks about firewall access, allow Python on the private network. The Raspberry Pi must be able to reach port `5000` on the laptop.

## Dashboard Options

The easiest dashboard is served by Flask:

```text
http://<WINDOWS_LAPTOP_IP>:5000
```

You can also open this standalone file:

```text
dashboard/rover_dashboard_windows.html
```

Before using the standalone file, edit:

```js
const WINDOWS_LAPTOP_IP = "<WINDOWS_LAPTOP_IP>";
```

## Recommended Startup Order

1. Plug the USB webcam into the Raspberry Pi.
2. Configure `server/vision_config.json` and set the selected provider API key, or enable Ollama/LM Studio.
3. Start `server/security_rover_server_windows.py` on the Windows laptop.
4. Note the Windows IP printed by Flask, for example `10.139.244.74`.
5. Edit `rover/rpi2b/config.json` with that Windows/server IP.
6. Run `python rover_client.py --config config.json` on the Pi.
7. Open `http://<WINDOWS_LAPTOP_IP>:5000` in the browser.
8. Confirm the Pi webcam feed appears, then click the map to send a rover goal.

## Demo Behavior Targets

The dashboard and rover protocol now support the core demo actions:

```text
Manual dashboard control
Clicked map goals
Immediate stop
Return-to-home
Ultrasonic scan
Multimodal event alerts
```

The dashboard includes green-strip search and go-to-green-strip controls. Marker detections are stored against the rover's current map position, so the rover can drive back to the last seen strip when commanded. The next behavior layer should add richer patrol scripts around those stored marker points.

## Calibration Notes

The rover has no wheel encoders, so forward distance is open-loop and approximate.

Tune this in `rover/rpi2b/config.json`:

```json
{
  "motion": {
    "drive_ms_per_cm": 50.0
  }
}
```

If the rover drives too far, lower it. If it stops short, raise it.

Tune turning with:

```json
{
  "motion": {
    "turn_kp": 0.8,
    "turn_tolerance_deg": 5.0,
    "turn_min_pwm": 35.0,
    "turn_max_pwm": 85.0
  }
}
```

If turning oscillates, lower `turn_kp`. If turning is too weak, raise `turn_min_pwm` or `turn_kp`.

## Compatibility Checklist

```text
Camera stream endpoint:      /camera.mjpg from the latest Pi webcam frame
Rover WebSocket endpoint:    /ws/rover
Primary rover ID:            rpi2b_rover
Pi camera frame event:       {"type":"camera_frame","format":"jpeg","image_b64":"..."}
Server vision result event:  {"type":"vision_result","detected":true,...}
Pi vision decision event:    {"type":"vision_decision","action":"stop_and_alert",...}
Dashboard goal event:        set_goal
Dashboard return event:      return_home
Dashboard scan event:        request_scan
Server alert event:          new_alert
Server position event:       rover_position
Rover scan command:          {"cmd":"scan"}
Rover stop command:          {"cmd":"stop"}
Rover navigation command:    {"cmd":"goto","angle":...,"distance":...}
```

## Troubleshooting

If the Pi cannot connect to the server:

```text
1. Confirm the laptop and Pi are on the same network.
2. Confirm the server is running on 0.0.0.0:5000.
3. Confirm Windows Firewall allows Python on the private network.
4. Confirm config.json server_host is the laptop IP, not the camera IP.
```

If I2C sensors are not detected:

```bash
sudo apt install -y i2c-tools
i2cdetect -y 1
```

Expected addresses:

```text
MPU6050:          0x68
GY-271/HMC5883L: 0x1E
```

If the rover reports `imu_error`, the Pi does not have a usable compass or MPU6050 heading source. Fix I2C wiring, enable I2C, or confirm the sensor addresses in `config.json`.

If motors move backward, swap the motor leads or swap the forward/reverse pins for that side in `config.json`.

If the Pi reboots when motors or the servo move, power motors and servo from a separate supply and keep grounds common.

## Verification Notes

The active Python rover client can be syntax-checked with:

```bash
python -m py_compile rover/rpi2b/rover_client.py
```

The laptop server files can be syntax-checked with:

```powershell
python -m py_compile .\server\security_rover_server.py .\server\security_rover_server_windows.py
```

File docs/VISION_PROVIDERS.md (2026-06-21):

---
title: Vision Providers
---

# Multimodal Vision Providers

STASIS can use a cloud multimodal API, a local Ollama model, LM Studio, or the original local Gemma path. The Raspberry Pi still captures the USB webcam and sends frames to the Windows laptop. The Windows laptop sends each selected frame to the configured vision provider, receives JSON, and sends the result back to the Raspberry Pi so the rover can decide what to do.

Use this when local Gemma is too heavy for your laptop, when Torch is not installing cleanly, or when you want to test several multimodal models without changing Python code.

## Recommended Demo Setup

For the smoothest local demo, start with the Moondream two-stage Ollama setup. Keep cloud APIs as backup if the competition network allows them.

```text
Raspberry Pi webcam frame
  -> Windows server
  -> Moondream checks the image
  -> tiny text model converts the notes into STASIS JSON
  -> if local models fail, try Gemini / OpenAI / Qwen / Zhipu / Anthropic / Kimi API
  -> Raspberry Pi receives vision_result
  -> Raspberry Pi decides stop, alert, marker memory, or continue
```

## Setup

On Windows:

```powershell
cd server
copy vision_config.example.json vision_config.json
py -m venv .venv
.\.venv\Scripts\activate
python -m pip install --upgrade pip
pip install -r requirements-api.txt
```

Open `server/vision_config.json` and turn on the provider you want:

```json
"gemini": {
  "type": "gemini",
  "enabled": true,
  "api_key_env": "GEMINI_API_KEY",
  "base_url": "https://generativelanguage.googleapis.com/v1beta",
  "model": "gemini-2.5-flash-lite"
}
```

Set the matching API key in the same PowerShell window before starting the server:

```powershell
$env:GEMINI_API_KEY = "your_key_here"
python security_rover_server_windows.py
```

Do not put real API keys directly into GitHub. The real `server/vision_config.json` file is ignored by Git.

## Provider Order

The server tries providers in this order:

```json
"provider_order": [
  "gemini",
  "openai",
  "qwen_dashscope",
  "zhipu",
  "ollama",
  "lmstudio"
]
```

Only enabled providers are used. If a provider fails, STASIS logs the error and tries the next enabled provider.

## Recommended Local Setup: Moondream + Tiny Text Model

Gemma 4 E2B is accurate but can be too slow on a laptop during a live robot demo. The recommended local setup splits the work into two smaller jobs:

```text
Moondream       -> looks at the camera frame
qwen2.5:0.5b    -> converts Moondream notes into clean STASIS JSON
```

Install the models:

```powershell
ollama pull moondream
ollama pull qwen2.5:0.5b
```

Enable this provider in `server/vision_config.json`:

```json
"moondream_stasis": {
  "type": "ollama_moondream_pipeline",
  "enabled": true,
  "base_url": "http://127.0.0.1:11434",
  "vision_model": "moondream",
  "text_model": "qwen2.5:0.5b",
  "jpeg_quality": 60,
  "vision_timeout_seconds": 20,
  "formatter_timeout_seconds": 15,
  "vision_max_tokens": 96,
  "formatter_max_tokens": 120,
  "use_text_formatter": true
}
```

Put it first:

```json
"provider_order": [
  "moondream_stasis",
  "gemini",
  "zhipu",
  "qwen_dashscope",
  "ollama",
  "lmstudio",
  "local_gemma"
]
```

Use this for the competition demo because it is faster and more focused than asking one large model to do every vision and explanation task.

## Supported Cloud Providers

The example config includes:

```text
gemini          Google Gemini API
openai          OpenAI vision-capable chat models
anthropic       Claude vision models
qwen_dashscope  Alibaba Cloud DashScope Qwen-VL models
kimi            Moonshot Kimi vision models, if available for your account
zhipu           Zhipu GLM vision models
```

Most of these providers use either the OpenAI-compatible chat format or their own official multimodal format. You can change `base_url`, `model`, and `api_key_env` in `vision_config.json` without touching code.

## Cheapest Or Free Options To Try

Prices and free quotas change, so check the official pricing page before the final demo. For your project, try them in this order:

1. Moondream + `qwen2.5:0.5b` through Ollama, free local setup with no API key.
2. Gemini API free tier or Flash-Lite style models, if your quota works.
3. Z.AI / Zhipu `glm-4.6v-flash`, which is a free vision model in their official pricing docs.
4. Alibaba DashScope `qwen3-vl-8b-instruct`, which is a low-cost Chinese multimodal model.
5. OpenAI small vision models, usually reliable and cheap but not normally free.
6. Anthropic Haiku vision models, good quality but usually paid.

If your Gemini quota is exhausted, keep Gemini in the config but put another provider before it in `provider_order`.

Official pricing pages to check before the demo:

```text
Google Gemini API: https://ai.google.dev/gemini-api/docs/pricing
Z.AI / Zhipu:      https://docs.z.ai/guides/overview/pricing
Alibaba Qwen:      https://www.alibabacloud.com/help/en/model-studio/model-pricing
OpenAI:            https://platform.openai.com/docs/pricing
Anthropic:         https://platform.claude.com/docs/en/about-claude/pricing
```

## Single-Model Ollama Fallback

If you want one Ollama model instead of the Moondream pipeline, install Ollama on the Windows laptop, then pull a vision-capable model:

```powershell
ollama pull llava:7b
```

Enable Ollama in `vision_config.json`:

```json
"ollama": {
  "type": "ollama",
  "enabled": true,
  "base_url": "http://127.0.0.1:11434",
  "model": "llava:7b"
}
```

Then put `ollama` near the end of `provider_order`. This makes it a backup when cloud APIs fail.

## LM Studio Fallback

In LM Studio:

1. Download a vision-capable model.
2. Start the local server.
3. Keep the server URL as `http://127.0.0.1:1234/v1`.
4. Set the exact model name in `vision_config.json`.

Example:

```json
"lmstudio": {
  "type": "openai_compatible",
  "enabled": true,
  "base_url": "http://127.0.0.1:1234/v1",
  "model": "your-loaded-vision-model",
  "json_mode": false
}
```

Some local models do not support strict JSON mode, so LM Studio defaults to `"json_mode": false`.

## Troubleshooting

If an OpenAI-compatible provider says `response_format` is not supported, set this for that provider:

```json
"json_mode": false
```

The STASIS prompt still asks for JSON, and the server parser will extract the first JSON object from normal text.

## Local Gemma

The original local Gemma path is still available, but it needs the full heavy install:

```powershell
pip install -r requirements-windows.txt
```

Then enable:

```json
"local_gemma": {
  "type": "local_gemma",
  "enabled": true,
  "model": "google/gemma-4-E2B-it",
  "pipeline_task": "any-to-any"
}
```

Use this only if your laptop has enough RAM and the model starts reliably. API mode does not need Torch.

## What The Model Must Return

Every provider is asked to return this JSON:

```json
{"detected": true, "category": "human", "message": "person visible near the Green Strip"}
```

Allowed categories:

```text
human
animal
track
fire
marker
```

The server filters anything outside those categories so the project does not drift away from the STASIS mission.

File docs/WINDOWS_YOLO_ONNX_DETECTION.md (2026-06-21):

---
title: Windows YOLO ONNX Detection
---

# Windows YOLO ONNX Detection

This is the recommended STASIS demo setup when the Raspberry Pi 2B cannot run YOLO/Torch.

## What Runs Where

```text
Raspberry Pi 2B
  - streams USB webcam frames
  - receives rover commands
  - controls motors and sensors

Windows laptop
  - hosts dashboard
  - receives Pi camera stream
  - runs YOLO ONNX object detection
  - creates human, animal, and object alerts
  - sends vision_result commands back to the Pi
```

This avoids installing `torch` or `ultralytics` on the Pi.

## Windows Setup

From the repo root on Windows:

```powershell
cd server
python -m pip install -r requirements-object-detection.txt
```

Put the ONNX model here:

```text
server/models/yolo11n.onnx
```

If you only have `yolo11n.pt`, export it on Windows, not on the Pi:

```powershell
python -m pip install ultralytics
yolo export model=yolo11n.pt format=onnx imgsz=640 simplify=True
mkdir models
move yolo11n.onnx models\yolo11n.onnx
```

Start the Windows server:

```powershell
$env:STASIS_CAMERA_SOURCE = "rover"
$env:STASIS_OBJECT_REVIEW_PROVIDER = "fallback"
$env:STASIS_YOLO_ONNX_MODEL = "models/yolo11n.onnx"
python security_rover_server_object_detection.py
```

## False-Positive Filtering

The YOLO model is not retrained. STASIS makes it stricter with server-side post-processing in `server/detection_filtering.py`.

Tune the central config in `server/detection_filter_config.json`, or point `STASIS_DETECTION_FILTER_CONFIG` at another JSON file. The default gate is intentionally conservative:

```text
Human confidence: 0.70
Object/wildlife confidence: 0.75
Persistence: 5 consecutive stable frames
Minimum box area: 2% of the frame
Edge exclusion: top/bottom 10%, left/right 5%
Duplicate alert cooldown: 10 seconds
```

Dashboard detections appear first as Detection Candidate. Only Confirmed Detection entries can trigger alerts, screenshots, notifications, rover commands, or saved alert records.

Open:

```text
http://192.168.29.69:5000
```

Use your current Windows IP if it changes.

## Raspberry Pi Setup

The Pi does not need YOLO, Torch, Ultralytics, or ONNX Runtime.

Run the normal rover client:

```bash
cd ~/Documents/Stasis/rover/rpi2b
source .venv/bin/activate
python rover_client.py --config config.json
```

Make sure `config.json` points to the Windows laptop:

```json
"server_host": "192.168.29.69"
```

## Expected Result

When the Pi webcam sees a person, animal, or object:

```text
Windows terminal: Windows YOLO detections: ...
Dashboard: alert card appears
Map: dot appears
Track: shows forward/left/right guidance in centimeters
Pi: receives vision_result and can stop for human/fire
```

## If No Alert Appears

Check these first:

```powershell
dir server\models
python -c "import onnxruntime; print('onnxruntime ok')"
```

The server terminal must say:

```text
Windows YOLO ONNX detector loaded from ...
```

If it says the model is missing, put `yolo11n.onnx` in `server/models/`.

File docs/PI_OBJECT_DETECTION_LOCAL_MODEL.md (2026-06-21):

---
title: Pi Object Detection Local Model
---

# Pi Object Detection Local Model

STASIS can run a Pi-only detector when the demo must work without laptop-side AI.
For the fastest demo, use the Windows laptop-side detector instead and keep the Pi as the camera and motor controller.

For best Pi 2B behavior, use the combined detector:

```text
custom YOLO model -> your demo objects
OpenCV COCO model -> person + cell phone
Green Strip detector -> optional color marker
```

This lets your custom model stay focused on your demo objects while the older COCO detector covers humans and mobile phones.

## Recommended Profiles

Use a known-good profile instead of hand-editing detection values every run:

```bash
cd ~/Documents/Stasis/rover/rpi2b
cp profiles/demo_stable_pi.json config.json
nano config.json
```

Set only `server_host` to the Windows laptop IP. Keep `input_size` at `320` for the current NCNN export.

Available profiles:

```text
profiles/demo_stable_pi.json  - recommended demo profile
profiles/demo_fast_pi.json    - lower stream resolution and faster detection cadence
profiles/debug_verbose.json   - loose thresholds and detection debug output
```

The stable profile uses these important values inside `object_detection`:

```json
{
  "backend": "combined",
  "yolo_model_path": "models/best_ncnn_model",
  "target_classes": ["debit card", "green strip", "paper", "plastic covers", "plastic water bottle", "steel water bottle", "torch", "wallet", "wood"],
  "common_detection_enabled": true,
  "common_target_classes": ["person", "cell phone"],
  "common_detection_every_n": 2,
  "class_names_path": "models/coco.names",
  "config_path": "models/ssd_mobilenet_v3_large_coco_2020_01_14.pbtxt",
  "weights_path": "models/frozen_inference_graph.pb",
  "confidence_threshold": 35,
  "nms_threshold": 20,
  "input_size": 320,
  "max_box_area_percent": 90.0,
  "overlay_enabled": false,
  "stream_interval_seconds": 0.12,
  "stream_jpeg_quality": 50,
  "upload_interval_seconds": 1.5
}
```

If your custom model is an exported NCNN folder, set:

```json
"yolo_model_path": "models/best_ncnn_model"
```

With an NCNN folder, the Pi client loads `model.ncnn.param` and `model.ncnn.bin` directly. It does not need Ultralytics for the custom model.

## Files Needed On The Pi

Put custom NCNN model here:

```text
~/Documents/Stasis/rover/rpi2b/models/best_ncnn_model/
```

The folder must contain:

```text
model.ncnn.param
model.ncnn.bin
metadata.yaml
```

Keep these COCO files too:

```text
~/Documents/Stasis/rover/rpi2b/models/coco.names
~/Documents/Stasis/rover/rpi2b/models/ssd_mobilenet_v3_large_coco_2020_01_14.pbtxt
~/Documents/Stasis/rover/rpi2b/models/frozen_inference_graph.pb
```

## Install

```bash
cd ~/Documents/Stasis/rover/rpi2b
source .venv/bin/activate
pip install -r requirements.txt
pip install -r requirements-object-detection.txt
```

Only install Ultralytics if you are trying to run a `.pt` model directly on the Pi:

```bash
python -m pip install ultralytics
```

If this fails because of `torch`, use an exported model format that works on your Pi environment, or run only the OpenCV COCO detector with:

```json
"backend": "opencv"
```

## Run

```bash
cd ~/Documents/Stasis/rover/rpi2b
source .venv/bin/activate
python rover_client_object_detection.py --config config.json
```

Good startup logs should include:

```text
Pi-side YOLO object detector loaded
Pi-side COCO object detector loaded
Combined detector ready
WebSocket handshake successful
```

## What It Detects

Your custom model detects the classes it was trained with. For the current exported model, examples include:

```text
cardboard
debit card
green strip
paper
plastic covers
plastic water bottle
steel water bottle
torch
wallet
wood
```

The common model detects:

```text
person
cell phone
```

All detections are drawn on the livestream when `overlay_enabled` is `true`.

## Reliability Gate

Pi-side detections are still reviewed by the server post-processing gate before alerts are allowed. The Pi sends repeated detection telemetry so the server can confirm persistence across frames.

Tune `server/detection_filter_config.json` on the laptop. By default, alerts require:

```text
Human confidence: 0.70
Object/wildlife confidence: 0.75
Persistence: 5 consecutive stable frames
Minimum box area: 2% of the frame
Edge exclusion: top/bottom 10%, left/right 5%
Duplicate alert cooldown: 10 seconds
```

## Human Stop And Follow

When a human detection is confirmed by the server reliability gate, the Pi stops the L911S motors and sends a `vision_decision` to the dashboard. The dashboard then offers:

```text
Follow
Stay
Resume
```

`Follow` uses the human bounding box center to steer left/right and the box area as a rough distance signal. `Stop` on the dashboard always overrides follow, patrol, and goto.

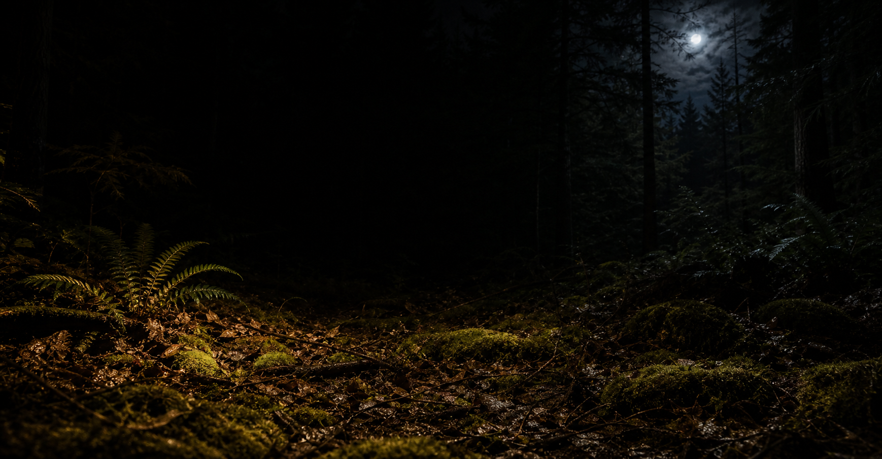
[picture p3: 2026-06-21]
docs/assets/stasis-forest-real.jpg

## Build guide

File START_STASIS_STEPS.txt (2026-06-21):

STASIS START AGAIN STEPS
========================

Use this when the rover must start from a known working state.

PART 1 - WINDOWS SERVER
-----------------------

1. Open PowerShell on the Windows laptop.

2. Start the server in Pi-authority mode:

cd C:\Users\haris\Downloads\Stasis-main\Stasis\server
$env:STASIS_DETECTION_AUTHORITY="pi"
$env:STASIS_OBJECT_REVIEW_PROVIDER="fallback"
$env:STASIS_PI_IGNORE_LABELS=""
$env:STASIS_PI_MIN_OBJECT_CONFIDENCE="0.35"
$env:STASIS_PI_MIN_COMMON_OBJECT_CONFIDENCE="0.35"
python security_rover_server_object_detection.py

3. Keep PowerShell open.

4. Open the dashboard:

http://127.0.0.1:5000

PART 2 - RASPBERRY PI CONFIG
----------------------------

1. Open terminal on Raspberry Pi.

2. Go to the Pi rover folder:

cd ~/Documents/Stasis/rover/rpi2b

3. Backup the current config:

cp config.json config.before_demo.json

4. Activate the stable demo profile:

cp profiles/demo_stable_pi.json config.json

5. Edit the Windows laptop IP:

nano config.json

Set:

"server_host": "YOUR_WINDOWS_LAPTOP_IP",

For example:

"server_host": "192.168.29.69",

PART 3 - MODEL FILES
--------------------

The custom NCNN model must be here:

models/best_ncnn_model/model.ncnn.param
models/best_ncnn_model/model.ncnn.bin
models/best_ncnn_model/metadata.yaml

The COCO person/phone files must be here:

models/coco.names
models/ssd_mobilenet_v3_large_coco_2020_01_14.pbtxt
models/frozen_inference_graph.pb

PART 4 - START PI ROVER
-----------------------

cd ~/Documents/Stasis/rover/rpi2b
source .venv/bin/activate
python rover_client_object_detection.py --config config.json

Good logs:

Configuration successfully loaded
Pi-side NCNN YOLO detector loaded
Pi-side COCO object detector loaded
Combined detector ready
WebSocket handshake successful
Streaming Pi webcam smoothly

PART 5 - DEMO BEHAVIOR
----------------------

Human detected:

1. Rover immediately stops.
2. Dashboard shows alert.
3. Choose Follow, Stay, or Resume.

Follow:

Rover follows the latest human bounding box with simple left/right steering.
If the target disappears, it stops.

Stop:

Dashboard Stop always cancels motion and stops motors.

Green strip:

Dashboard stores the marker and can go to it after it is seen.

PART 6 - IF IT BREAKS
---------------------

Use debug profile:

cp profiles/debug_verbose.json config.json
nano config.json
python rover_client_object_detection.py --config config.json

Then send Codex:

1. Pi terminal output.
2. Windows server output.
3. A screenshot of the dashboard Detections panel.

PART 7 - ALL SENSOR MODE
------------------------

Use this only after the ultrasonic sensor, scanner servo, MPU6050, and compass are physically connected.

cd ~/Documents/Stasis/rover/rpi2b
cp config.json config.before_all_sensors.json
cp profiles/demo_all_sensors_pi.json config.json
nano config.json

Set server_host to the Windows laptop IP.

Run:

source .venv/bin/activate
python rover_client_object_detection.py --config config.json

The all-sensors profile enables:

- direct Raspberry Pi GPIO motor control
- USB webcam
- custom NCNN YOLO object detection
- COCO person/cell-phone detection
- HC-SR04 ultrasonic obstacle checks
- scanner servo sweep
- MPU6050
- HMC5883L/QMC5883L compass

If any optional component is missing, the rover should continue running camera streaming and object detection. Missing sensors or motor outputs will be logged as warnings and disabled.

Do not enable ESP32-S3 motor mode unless the L911S motor input wires are moved from the Pi GPIO pins to the ESP32-S3 GPIO pins.

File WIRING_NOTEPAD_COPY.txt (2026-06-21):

STASIS WIRE CONNECTIONS - NOTEPAD COPY
======================================

CURRENT ANSWER
--------------

Yes, the repo has been updated and pushed to GitHub.

Latest important commits:

1e51308 - Add wiring and runbook guide
9a6ed4e - Add fault tolerant all-sensors rover profile

Current recommended setup:

- Raspberry Pi 2B is the main rover controller.
- USB webcam connects to Raspberry Pi.
- Raspberry Pi runs object detection and sends data to Windows dashboard.
- L911S motor driver can be driven directly by Raspberry Pi GPIO.
- ESP32-S3 is optional. Use it only if you want it as a USB-Serial motor bridge.
- Missing sensors should not stop the whole project. Connected components work; missing components are skipped.

IMPORTANT POWER RULES
---------------------

1. Do NOT power DC motors from Raspberry Pi 5V.
2. Use a separate motor battery for the L911S motor driver.
3. Raspberry Pi GND, L911S GND, sensor GND, servo GND, and motor battery negative must share common ground.
4. Raspberry Pi GPIO pins are 3.3V logic.
5. HC-SR04 Echo is 5V. Use a voltage divider or level shifter before connecting Echo to Raspberry Pi GPIO.

RASPBERRY PI 2B PIN MAP
-----------------------

Use BCM GPIO numbers in code.

Function                         BCM GPIO     Physical Pin
----------------------------------------------------------
Left motor forward               GPIO5        Pin 29
Left motor reverse               GPIO6        Pin 31
Right motor forward              GPIO13       Pin 33
Right motor reverse              GPIO19       Pin 35
Ultrasonic trigger               GPIO23       Pin 16
Ultrasonic echo                  GPIO24       Pin 18
Scanner servo signal             GPIO18       Pin 12
I2C SDA                          GPIO2        Pin 3
I2C SCL                          GPIO3        Pin 5
3.3V sensor power                3V3          Pin 1 or 17
5V power                         5V           Pin 2 or 4
Ground                           GND          Pin 6, 9, 14, 20, 25, 30, 34, or 39

MINIMAL DEMO WIRING
-------------------

Use this if you want the simplest working rover.

Raspberry Pi USB port -> USB webcam

Raspberry Pi GPIO5  -> L911S A-IA
Raspberry Pi GPIO6  -> L911S A-IB
Raspberry Pi GPIO13 -> L911S B-IA
Raspberry Pi GPIO19 -> L911S B-IB

Raspberry Pi GND -> L911S GND
Motor battery positive -> L911S VCC / VM
Motor battery negative -> L911S GND
L911S Motor A output -> Left DC motor
L911S Motor B output -> Right DC motor

Do not connect ESP32-S3 motor pins in this mode.

L911S DIRECT RASPBERRY PI MOTOR WIRING
--------------------------------------

L911S Pin        Connect To
---------------------------
A-IA             Raspberry Pi GPIO5, physical pin 29
A-IB             Raspberry Pi GPIO6, physical pin 31
B-IA             Raspberry Pi GPIO13, physical pin 33
B-IB             Raspberry Pi GPIO19, physical pin 35
VCC / VM         Motor battery positive
GND              Motor battery negative and Raspberry Pi GND
Motor A output   Left DC motor
Motor B output   Right DC motor

Config:

"direct_motor_control": true
"esp32_serial_control": false

ESP32-S3 OPTIONAL MOTOR BRIDGE
------------------------------

Use ESP32-S3 only if you want this:

Raspberry Pi -> USB serial -> ESP32-S3 -> L911S -> motors

Do NOT connect Raspberry Pi motor GPIO pins and ESP32-S3 motor GPIO pins to the L911S at the same time.

Raspberry Pi To ESP32-S3:

Raspberry Pi USB port -> ESP32-S3 USB / UART port

ESP32-S3 To L911S:

ESP32-S3 GPIO4 -> L911S A-IA
ESP32-S3 GPIO5 -> L911S A-IB
ESP32-S3 GPIO6 -> L911S B-IA
ESP32-S3 GPIO7 -> L911S B-IB
ESP32-S3 GND   -> L911S GND

L911S power:

Motor battery positive -> L911S VCC / VM
Motor battery negative -> L911S GND
L911S Motor A output -> Left DC motor
L911S Motor B output -> Right DC motor

ESP32-S3 firmware:

rover/esp32_s3/stasis_motor_controller.ino

Serial:

Baud rate: 115200
Command format: M:left_speed,right_speed
Stop command: M:0,0

Config for ESP32-S3 motor mode:

"direct_motor_control": false
"esp32_serial_control": true
"esp32_serial_port": "/dev/ttyUSB0"
"esp32_baudrate": 115200

If Pi shows /dev/ttyACM0, use:

"esp32_serial_port": "/dev/ttyACM0"

USB WEBCAM
----------

Webcam USB cable -> Raspberry Pi USB port

Check camera:

ls /dev/video*

Config:

"camera": {
  "enabled": true,
  "index": 0
}

HC-SR04 ULTRASONIC SENSOR
-------------------------

HC-SR04 Pin      Connect To
---------------------------
VCC              5V
GND              Raspberry Pi GND
TRIG             GPIO23, physical pin 16
ECHO             GPIO24, physical pin 18 through voltage divider / level shifter

Config:

"ultrasonic_enabled": true

If ultrasonic is not connected, the rover skips ultrasonic and other parts continue.

SCANNER SERVO
-------------

Servo Wire       Connect To
---------------------------
Signal           GPIO18, physical pin 12
VCC              External 5V servo supply
GND              External supply GND and Raspberry Pi GND

Do not power a moving servo from Raspberry Pi 5V if it causes resets.

Config:

"scanner_servo_enabled": true

If servo is not connected, the rover skips servo and other parts continue.

MPU6050 IMU
-----------

MPU6050 Pin      Connect To
---------------------------
VCC              3.3V
GND              Raspberry Pi GND
SDA              GPIO2, physical pin 3
SCL              GPIO3, physical pin 5

Config:

"i2c_enabled": true
"mpu6050_enabled": true

If MPU6050 is not connected, the rover skips IMU and other parts continue.

HMC5883L / QMC5883L COMPASS
---------------------------

Compass Pin      Connect To
---------------------------
VCC              3.3V
GND              Raspberry Pi GND
SDA              GPIO2, physical pin 3
SCL              GPIO3, physical pin 5

Config:

"i2c_enabled": true
"compass_enabled": true

If compass is not connected, the rover skips compass and other parts continue.

ALL-SENSORS PROFILE
-------------------

Use this if all components may be connected, but you still want missing components to be skipped safely.

On Raspberry Pi:

cd ~/Documents/Stasis
git pull origin main

cd ~/Documents/Stasis/rover/rpi2b
cp config.json config.before_all_sensors.json
cp profiles/demo_all_sensors_pi.json config.json
nano config.json

Set server_host to Windows laptop IP:

"server_host": "YOUR_WINDOWS_IP"

Run:

source .venv/bin/activate
python rover_client_object_detection.py --config config.json

WINDOWS SERVER RUN COMMANDS
---------------------------

On Windows PowerShell:

cd C:\Users\haris\Downloads\Stasis-main\Stasis\server
$env:STASIS_DETECTION_AUTHORITY="pi"
$env:STASIS_OBJECT_REVIEW_PROVIDER="fallback"
$env:STASIS_PI_IGNORE_LABELS=""
$env:STASIS_PI_MIN_OBJECT_CONFIDENCE="0.20"
$env:STASIS_PI_MIN_COMMON_OBJECT_CONFIDENCE="0.35"
python security_rover_server_object_detection.py

Open dashboard:

http://WINDOWS_LAPTOP_IP:5000

EXPECTED GOOD LOGS
------------------

Pi-side NCNN YOLO detector loaded
Pi-side COCO object detector loaded
Combined detector ready
WebSocket handshake successful
Streaming Pi webcam smoothly

FAULT-TOLERANT BEHAVIOR
-----------------------

If ultrasonic is missing -> ultrasonic disabled, rest keeps working.
If servo is missing -> servo disabled, rest keeps working.
If MPU6050 is missing -> IMU disabled, rest keeps working.
If compass is missing -> compass disabled, rest keeps working.
If motor driver is missing -> motor output disabled, sensors/camera/object detection keep working.
If ESP32-S3 is missing but direct Pi motors are enabled -> ESP32-S3 is not needed.
If ESP32-S3 mode is enabled but ESP32-S3 is missing -> motor output disabled, camera/object detection keep working.

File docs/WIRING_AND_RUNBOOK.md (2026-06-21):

---
title: Wiring And Runbook
---

# STASIS Wiring And Runbook

This guide matches the current Raspberry Pi 2B rover code and `rover/rpi2b/config.json` pin names.

## Current Demo Hardware

Required:

- Raspberry Pi 2B
- USB webcam
- L911S / L9110S dual motor driver
- 4 DC motors, wired as two left-side motors and two right-side motors
- Separate motor battery pack
- Windows laptop running the STASIS dashboard server

Supported but not required for the current direct-Pi setup:

- ESP32-S3 as a USB-Serial motor bridge

Optional:

- HC-SR04 ultrasonic distance sensor
- SG90-style scanner servo
- MPU6050 IMU
- HMC5883L/QMC5883L compass module

## Important Power Rules

- Do not power motors from the Raspberry Pi 5V pin.
- Use a separate motor battery connected to the L911S motor power input.
- Connect Raspberry Pi GND and L911S GND together. Without common ground, motor control will be unreliable.
- Raspberry Pi GPIO pins are 3.3V logic. Do not feed 5V sensor output directly into a GPIO pin.
- If using HC-SR04, put a voltage divider or level shifter on the Echo pin before Raspberry Pi GPIO.

## Raspberry Pi 2B Pin Map

The code uses BCM GPIO numbering, not physical board pin numbers.

| Function | BCM GPIO | Physical Pin |
| --- | ---: | ---: |
| Left motor forward | GPIO5 | Pin 29 |
| Left motor reverse | GPIO6 | Pin 31 |
| Right motor forward | GPIO13 | Pin 33 |
| Right motor reverse | GPIO19 | Pin 35 |
| Ultrasonic trigger | GPIO23 | Pin 16 |
| Ultrasonic echo | GPIO24 | Pin 18 |
| Scanner servo signal | GPIO18 | Pin 12 |
| I2C SDA | GPIO2 | Pin 3 |
| I2C SCL | GPIO3 | Pin 5 |
| 3.3V sensor power | 3V3 | Pin 1 or 17 |
| 5V power | 5V | Pin 2 or 4 |
| Ground | GND | Pin 6, 9, 14, 20, 25, 30, 34, or 39 |

## L911S Motor Driver Wiring

Use this for the current `direct_motor_control` mode. This is the mode currently used by the demo config.

The code controls two motor channels: left side and right side. Your rover has four physical motors, so both left motors share the left-side channel and both right motors share the right-side channel. Before wiring two motors to one channel, confirm your L911S/L9110S board and motor battery can safely handle the combined stall current.

| L911S Pin | Connect To |
| --- | --- |
| A-IA | Raspberry Pi GPIO5, physical pin 29 |
| A-IB | Raspberry Pi GPIO6, physical pin 31 |
| B-IA | Raspberry Pi GPIO13, physical pin 33 |
| B-IB | Raspberry Pi GPIO19, physical pin 35 |
| VCC / VM | Motor battery positive |
| GND | Motor battery negative and Raspberry Pi GND |
| Motor A output | Both left-side DC motors |
| Motor B output | Both right-side DC motors |

If left/right movement is reversed, swap the two wires for the affected side or swap the matching forward/reverse GPIO values in the config.

## L298N Motor Driver Wiring

Use this now that the L911S B channel is damaged. One L298N board is enough for two-side differential drive: OUT1/OUT2 drives the left side and OUT3/OUT4 drives the right side. Since you have four L298N boards, keep the extras as spares unless you later decide to control each wheel independently.

Remove the ENA/ENB jumpers if you want Raspberry Pi speed control. If you leave the jumpers installed, the motors may only run full speed.

| L298N Pin | Connect To |
| --- | --- |
| IN1 | Raspberry Pi GPIO5, physical pin 29 |
| IN2 | Raspberry Pi GPIO6, physical pin 31 |
| IN3 | Raspberry Pi GPIO13, physical pin 33 |
| IN4 | Raspberry Pi GPIO19, physical pin 35 |
| ENA | Raspberry Pi GPIO12, physical pin 32 |
| ENB | Raspberry Pi GPIO20, physical pin 38 |
| 12V / +V motor input | Motor battery positive, matched to your motors |
| GND | Motor battery negative and Raspberry Pi GND |
| 5V logic | Leave alone if the board has onboard 5V regulator enabled; otherwise use the board's documented 5V logic input |
| OUT1 / OUT2 | Left-side motor or left-side motor pair |
| OUT3 / OUT4 | Right-side motor or right-side motor pair |

Pi config for L298N:

```json
"hardware": {
  "direct_motor_control": true,
  "motor_driver": "l298n"
},
"pins": {
  "left_motor_forward": 5,
  "left_motor_reverse": 6,
  "right_motor_forward": 13,
  "right_motor_reverse": 19,
  "left_motor_enable": 12,
  "right_motor_enable": 20
}
```

If you keep ENA/ENB jumpers installed, set both enable pins to `null`.

## ESP32-S3 Motor Bridge Wiring

The repo still supports the ESP32-S3, but it is optional. It is not used for the current direct-Pi demo unless you enable `esp32_serial_control`.

Use the ESP32-S3 only if you want this topology:

```text
Raspberry Pi -> USB serial -> ESP32-S3 -> L911S -> motors
```

In this mode:

- The Raspberry Pi still runs the camera, object detection client, dashboard link, and high-level rover decisions.
- The ESP32-S3 only receives serial speed commands and generates PWM for the L911S motor driver.
- Do not wire the same L911S input pins to both the Raspberry Pi and ESP32-S3 at the same time.

### Raspberry Pi To ESP32-S3

| Raspberry Pi | ESP32-S3 |
| --- | --- |
| USB port | ESP32-S3 USB/UART port |

After connecting, the Pi usually sees the ESP32-S3 as:

```text
/dev/ttyUSB0
```

or:

```text
/dev/ttyACM0
```

Check with:

```bash
ls /dev/ttyUSB* /dev/ttyACM*
```

### ESP32-S3 To L911S

These pins match `rover/esp32_s3/stasis_motor_controller.ino`.

| ESP32-S3 GPIO | L911S Pin | Purpose |
| ---: | --- | --- |
| GPIO4 | A-IA | Left motor forward |
| GPIO5 | A-IB | Left motor reverse |
| GPIO6 | B-IA | Right motor forward |
| GPIO7 | B-IB | Right motor reverse |
| GND | GND | Common ground |

L911S power and motor wiring stays the same:

| L911S Pin | Connect To |
| --- | --- |
| VCC / VM | Motor battery positive |
| GND | Motor battery negative, ESP32-S3 GND, and Raspberry Pi GND |
| Motor A output | Both left-side DC motors |
| Motor B output | Both right-side DC motors |

### ESP32-S3 Firmware

Flash this file to the ESP32-S3:

```text
rover/esp32_s3/stasis_motor_controller.ino
```

Serial settings:

```text
Baud rate: 115200
Command format: M:left_speed,right_speed
Example: M:80,-80
Stop: M:0,0
```

### Pi Config For ESP32-S3 Mode

Set the hardware section like this:

```json
"hardware": {
  "direct_motor_control": false,
  "esp32_serial_control": true,
  "esp32_serial_port": "/dev/ttyUSB0",
  "esp32_baudrate": 115200
}
```

If your Pi shows `/dev/ttyACM0`, use:

```json
"esp32_serial_port": "/dev/ttyACM0"
```

For the current simplest demo, keep ESP32-S3 disabled:

```json
"hardware": {
  "direct_motor_control": true,
  "esp32_serial_control": false
}
```

## USB Webcam Wiring

No jumper wires are needed.

| Webcam | Connect To |
| --- | --- |
| USB cable | Raspberry Pi USB port |

The config uses:

```json
"camera": {
  "enabled": true,
  "index": 0
}
```

If the camera is not found, test on the Pi:

```bash
ls /dev/video*
```

## HC-SR04 Ultrasonic Sensor Wiring

This is optional. The current demo profile keeps it disabled until connected.

| HC-SR04 Pin | Connect To |
| --- | --- |
| VCC | 5V |
| GND | Raspberry Pi GND |
| TRIG | GPIO23, physical pin 16 |
| ECHO | GPIO24, physical pin 18 through a voltage divider / level shifter |

Config when connected:

```json
"hardware": {
  "ultrasonic_enabled": true
}
```

## Scanner Servo Wiring

This is optional. Use it only if the camera/sensor is mounted on a servo.

| Servo Wire | Connect To |
| --- | --- |
| Signal | GPIO18, physical pin 12 |
| VCC | External 5V servo supply |
| GND | External supply GND and Raspberry Pi GND |

Do not power a moving servo from the Raspberry Pi 5V pin if it causes resets.

Config when connected:

```json
"hardware": {
  "scanner_servo_enabled": true
}
```

## MPU6050 IMU Wiring

This is optional. It uses I2C.

| MPU6050 Pin | Connect To |
| --- | --- |
| VCC | 3.3V |
| GND | Raspberry Pi GND |
| SDA | GPIO2, physical pin 3 |
| SCL | GPIO3, physical pin 5 |

Config when connected:

```json
"hardware": {
  "i2c_enabled": true,
  "mpu6050_enabled": true
}
```

## HMC5883L / QMC5883L Compass Wiring

This is optional. It also uses I2C.

| Compass Pin | Connect To |
| --- | --- |
| VCC | 3.3V |
| GND | Raspberry Pi GND |
| SDA | GPIO2, physical pin 3 |
| SCL | GPIO3, physical pin 5 |

Config when connected:

```json
"hardware": {
  "i2c_enabled": true,
  "compass_enabled": true
}
```

## Minimal Demo Wiring

For the current working demo, wire only:

```text
Raspberry Pi USB -> webcam
GPIO5  -> L911S A-IA
GPIO6  -> L911S A-IB
GPIO13 -> L911S B-IA
GPIO19 -> L911S B-IB
Pi GND -> L911S GND
Motor battery + -> L911S motor VCC/VM
Motor battery - -> L911S GND
L911S Motor A outputs -> two left-side DC motors
L911S Motor B outputs -> two right-side DC motors
```

Leave ultrasonic, servo, MPU6050, and compass disabled unless they are physically connected.

The Pi client initializes each hardware group separately. If one optional part is disabled or unavailable, the rest of the rover can still run: missing ultrasonic/servo hardware does not stop motor control, missing I2C sensors do not stop camera/object detection, and missing motors do not stop the camera or sensor checks.

Do not add ESP32-S3 wiring in this minimal mode. Add ESP32-S3 only if you switch to serial motor mode.

## Run The Windows Server

Open PowerShell on the Windows laptop:

```powershell
cd C:\Users\haris\Downloads\Stasis-main\Stasis\server
$env:STASIS_DETECTION_AUTHORITY="pi"
$env:STASIS_OBJECT_REVIEW_PROVIDER="fallback"
$env:STASIS_PI_IGNORE_LABELS=""
$env:STASIS_PI_MIN_OBJECT_CONFIDENCE="0.20"
$env:STASIS_PI_MIN_COMMON_OBJECT_CONFIDENCE="0.35"
python security_rover_server_object_detection.py
```

Find the laptop IP:

```powershell
ipconfig
```

Open the dashboard:

```text
http://<WINDOWS_LAPTOP_IP>:5000
```

## Run The Raspberry Pi Rover

Open terminal on the Pi:

```bash
cd ~/Documents/Stasis
git pull origin main

cd ~/Documents/Stasis/rover/rpi2b
source .venv/bin/activate
nano config.json
```

Set `server_host` to the Windows laptop IP:

```json
"server_host": "10.68.233.74"
```

Start the rover:

```bash
python rover_client_object_detection.py --config config.json
```

Good startup logs:

```text
Pi-side NCNN YOLO detector loaded
Pi-side COCO object detector loaded
Combined detector ready
WebSocket handshake successful
Streaming Pi webcam smoothly
```

## Enable Every Sensor

Use this only after the ultrasonic sensor, scanner servo, MPU6050, and compass are physically wired.

The rover is fault-tolerant in this mode. If a sensor is enabled in config but not physically detected, startup continues and the missing part is disabled. Camera streaming and object detection should still run.

```bash
cd ~/Documents/Stasis/rover/rpi2b
cp config.json config.before_all_sensors.json
cp profiles/demo_all_sensors_pi.json config.json
nano config.json
```

Set:

```json
"server_host": "<WINDOWS_LAPTOP_IP>"
```

Then run:

```bash
source .venv/bin/activate
python rover_client_object_detection.py --config config.json
```

Expected all-sensor startup logs:

```text
Direct GPIO motor driver setup complete
MPU6050 initialized
HMC5883L compass initialized
Streaming Pi webcam smoothly
Combined detector ready
WebSocket handshake successful
```

If something is missing, acceptable warning logs include:

```text
MPU6050 sensor not found on I2C bus; heading tracking disabled.
HMC5883L compass sensor not found on I2C bus; compass disabled.
Failed to configure Ultrasonic rangefinder.
Failed to configure SG90 scanner servo.
Direct GPIO motor driver unavailable; continuing without motor output.
ESP32-S3 serial motor controller unavailable; continuing without motor output.
```

Those warnings mean the connected parts still run, while missing parts are skipped.

If the servo and ultrasonic are enabled together, dashboard `scan` commands sweep the servo and read distance samples. If ultrasonic is enabled, forward driving stops when distance is below `obstacle_stop_distance_cm`.

## ESP32-S3 Or Direct Pi Motors

Choose exactly one motor mode:

```text
Option A: Raspberry Pi GPIO -> L911S
Option B: Raspberry Pi USB -> ESP32-S3 -> L911S
```

Do not connect both Raspberry Pi motor GPIO pins and ESP32-S3 motor GPIO pins to the L911S inputs at the same time.

The all-sensors profile uses Option A by default:

```json
"direct_motor_control": true,
"esp32_serial_control": false
```

To use ESP32-S3 motor control instead, first move the L911S input wires from the Pi GPIO pins to ESP32-S3 GPIO4/GPIO5/GPIO6/GPIO7, then change:

```json
"direct_motor_control": false,
"esp32_serial_control": true,
"esp32_serial_port": "/dev/ttyUSB0",
"esp32_baudrate": 115200
```

## Current Detection Setup

The current stable setup is:

```json
"backend": "combined",
"yolo_model_path": "models/best_ncnn_model",
"common_detection_enabled": true,
"common_target_classes": ["person", "cell phone"]
```

This means:

- Custom NCNN model detects demo objects and green strip.
- COCO detector detects person and cell phone.
- Dashboard receives both through the Pi WebSocket.

## Quick Troubleshooting

No dashboard:

```bash
ping <WINDOWS_LAPTOP_IP>
```

No Pi connection on dashboard:

```bash
grep server_host config.json
python rover_client_object_detection.py --config config.json
```

No camera:

```bash
ls /dev/video*
```

Motors do not move:

- Check common ground between Pi and L911S.
- Check motor battery voltage.
- Check BCM pin numbers, not physical pin numbers.
- Try swapping motor output wires if direction is reversed.

False detections:

- Raise `confidence_threshold`.
- Raise `min_box_area_percent`.
- Use better lighting.
- Keep trained objects closer and centered.

Slow detections:

- Use 320x240 camera resolution.
- Keep `upload_interval_seconds` around `0.5`.
- Set `common_detection_every_n` to `4` if COCO slows the Pi.

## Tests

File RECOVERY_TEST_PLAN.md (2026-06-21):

# STASIS Recovery & Test Plan

This document outlines the recovery and testing plan to ensure the STASIS rover project maintains a known working state.

## 1. Current Stable Architecture
* Raspberry Pi 2B handles camera streaming, motor control, and sensor readings.
* Laptop/base station handles dashboard.
* AI is currently disabled.
* `DETECTOR_BACKEND = "none"`
* `VISION_ENABLED = False`

## 2. How to Start the Server
* **Command to run:**
  ```powershell
  cd server
  python security_rover_server.py
  ```
* **Expected URL:** `http://127.0.0.1:5000`
* **Expected successful output:** Standard Flask/eventlet output indicating the server is running on `http://127.0.0.1:5000` with no critical errors or missing module tracebacks.

## 3. Manual Test Checklist
* [ ] Dashboard loads
* [ ] Stream panel appears
* [ ] Rover controls visible
* [ ] Sensor panel visible
* [ ] No AI imports required
* [ ] No repeated server errors

## 4. Things Not Allowed During Baseline Recovery
* No YOLOE
* No torch
* No cv2 requirement at startup
* No old UI restore
* No full refactor
* No deleting model files

## 5. Future Milestone Order
1. Baseline dashboard
2. Stream
3. Controls
4. Sensors
5. Logging
6. Detector backend none/custom/yoloe
7. False-positive filtering
8. YOLOE laptop-only experiment

## 6. Rollback Instructions
* Use the latest working commit
* Use the baseline tag if present
* Never force-push main

## Branch Safety Rules
- Do not work directly on main.
- Use separate branches for stream, controls, sensors, and detection.
- Merge only one branch at a time after testing.
- If a branch breaks the app, abandon the branch instead of fixing main.

## Known Working Baseline
- Record the commit hash of the current working dashboard baseline.
- Record the tag name if created: baseline-working-dashboard

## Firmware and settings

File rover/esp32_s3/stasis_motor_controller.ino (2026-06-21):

/**
 * @file stasis_motor_controller.ino
 * @brief ESP32-S3 Motor Controller for STASIS Forest Monitoring Rover
 * 
 * This firmware runs on an ESP32-S3 microcontroller. Its sole responsibility is 
 * to receive serial motor speed commands (left and right channel) from a host device 
 * (e.g., a Raspberry Pi) and drive an L911S dual-channel H-bridge motor driver.
 * 
 * Communication Protocol:
 * - Baud Rate: 115200 baud
 * - Command format: "M:left_speed,right_speed\n"
 *   - 'M' is the command prefix.
 *   - 'left_speed' and 'right_speed' are integers in the range [-100, 100].
 *   - Example: "M:80,-80\n" (Left forward 80%, Right reverse 80%)
 *   - Example: "M:0,0\n" (Stop both motors)
 * 
 * Safety Features:
 * - Failsafe Timeout: If no valid command is received within 2000 milliseconds,
 *   the controller will automatically stop all motors to prevent a runaway condition.
 * 
 * L911S H-Bridge Driver Logic:
 * - Left Motor:
 *   - Forward: Pin A-IA = PWM, Pin A-IB = LOW
 *   - Reverse: Pin A-IA = LOW, Pin A-IB = PWM
 *   - Stop:    Pin A-IA = LOW, Pin A-IB = LOW
 * - Right Motor:
 *   - Forward: Pin B-IA = PWM, Pin B-IB = LOW
 *   - Reverse: Pin B-IA = LOW, Pin B-IB = PWM
 *   - Stop:    Pin B-IA = LOW, Pin B-IB = LOW
 */

#include <Arduino.h>

// ==========================================
// CONFIGURATION & PIN DEFINITIONS
// ==========================================

// ESP32-S3 GPIO Pins connected to the L911S driver.
// Adjust these pins according to your physical wiring.
#define PIN_LEFT_MOTOR_IA  4   // Left Motor Input A (Forward Control)
#define PIN_LEFT_MOTOR_IB  5   // Left Motor Input B (Reverse Control)
#define PIN_RIGHT_MOTOR_IA 6   // Right Motor Input A (Forward Control)
#define PIN_RIGHT_MOTOR_IB 7   // Right Motor Input B (Reverse Control)

// Serial Communication Settings
#define SERIAL_BAUD_RATE   115200
#define SERIAL_TIMEOUT_MS  50

// Safety Failsafe Settings
#define FAILSAFE_TIMEOUT_MS 2000 // Stop motors if no serial message for 2 seconds

// PWM Configuration
#define PWM_FREQ           1000  // 1 kHz frequency (standard for DC motors)
#define PWM_RESOLUTION     8     // 8-bit resolution (0-255 duty cycle)

// ==========================================
// STATE VARIABLES
// ==========================================
unsigned long lastCommandTime = 0; // Tracks the last time a valid command was received
bool failsafeTriggered = false;    // Safety state flag

// ==========================================
// FUNCTION PROTOTYPES
// ==========================================
void setupMotors();
void setMotorSpeeds(int leftSpeed, int rightSpeed);
void processSerialInput();
void handleFailsafe();
void writePWM(uint8_t pin, int dutyCycle);

/**
 * @brief Initialize hardware interfaces.
 */
void setup() {
  // Initialize Serial interface
  Serial.begin(SERIAL_BAUD_RATE);
  Serial.setTimeout(SERIAL_TIMEOUT_MS);
  
  // Wait briefly for serial to stabilize (useful for ESP32-S3 USB OTG)
  delay(500);
  Serial.println("\n--- STASIS ESP32-S3 Motor Controller Initialized ---");
  Serial.println("Protocol: M:left,right\\n (Speeds from -100 to 100)");

  // Initialize GPIO pins for motor driving
  setupMotors();
  
  // Initialize the failsafe timer
  lastCommandTime = millis();
}

/**
 * @brief Main execution loop.
 */
void loop() {
  // 1. Check for incoming serial commands and process them
  processSerialInput();
  
  // 2. Validate failsafe condition
  handleFailsafe();
}

/**
 * @brief Configure GPIO motor pins.
 * 
 * Supports both older and newer ESP32 core versions using native PWM methods.
 */
void setupMotors() {
  pinMode(PIN_LEFT_MOTOR_IA, OUTPUT);
  pinMode(PIN_LEFT_MOTOR_IB, OUTPUT);
  pinMode(PIN_RIGHT_MOTOR_IA, OUTPUT);
  pinMode(PIN_RIGHT_MOTOR_IB, OUTPUT);
  
  // Ensure all pins start at LOW (motors stopped)
  digitalWrite(PIN_LEFT_MOTOR_IA, LOW);
  digitalWrite(PIN_LEFT_MOTOR_IB, LOW);
  digitalWrite(PIN_RIGHT_MOTOR_IA, LOW);
  digitalWrite(PIN_RIGHT_MOTOR_IB, LOW);

#if defined(ESP_ARDUINO_VERSION_MAJOR) && ESP_ARDUINO_VERSION_MAJOR >= 3
  // ESP32 Arduino Core 3.0.0+ uses ledcAttach and ledcWrite
  ledcAttach(PIN_LEFT_MOTOR_IA, PWM_FREQ, PWM_RESOLUTION);
  ledcAttach(PIN_LEFT_MOTOR_IB, PWM_FREQ, PWM_RESOLUTION);
  ledcAttach(PIN_RIGHT_MOTOR_IA, PWM_FREQ, PWM_RESOLUTION);
  ledcAttach(PIN_RIGHT_MOTOR_IB, PWM_FREQ, PWM_RESOLUTION);
#else
  // Older ESP32 cores (2.x) support analogWrite natively for PWM pin control.
  // We can write directly using analogWrite on ESP32 pins.
#endif
  
  Serial.println("Motor driver GPIO pins configured successfully.");
}

/**
 * @brief Safe analog/PWM output driver helper.
 * 
 * Handles core-independent duty writing.
 * 
 * @param pin The GPIO pin target
 * @param dutyCycle The 8-bit duty cycle value (0 to 255)
 */
void writePWM(uint8_t pin, int dutyCycle) {
  dutyCycle = constrain(dutyCycle, 0, 255);
#if defined(ESP_ARDUINO_VERSION_MAJOR) && ESP_ARDUINO_VERSION_MAJOR >= 3
  ledcWrite(pin, dutyCycle);
#else
  analogWrite(pin, dutyCycle);
#endif
}

/**
 * @brief Drive the L911S motor pins given left and right speed percentages.
 * 
 * @param leftSpeed Left motor speed (-100 to 100)
 * @param rightSpeed Right motor speed (-100 to 100)
 */
void setMotorSpeeds(int leftSpeed, int rightSpeed) {
  // Constrain inputs to legal ranges [-100, 100]
  leftSpeed = constrain(leftSpeed, -100, 100);
  rightSpeed = constrain(rightSpeed, -100, 100);

  // Convert speed percentage (0-100) to 8-bit PWM value (0-255)
  int leftPwm = map(abs(leftSpeed), 0, 100, 0, 255);
  int rightPwm = map(abs(rightSpeed), 0, 100, 0, 255);

  // --- Left Motor Direction Control ---
  if (leftSpeed > 0) {
    // Drive Left Forward
    writePWM(PIN_LEFT_MOTOR_IA, leftPwm);
    writePWM(PIN_LEFT_MOTOR_IB, 0);
  } else if (leftSpeed < 0) {
    // Drive Left Reverse
    writePWM(PIN_LEFT_MOTOR_IA, 0);
    writePWM(PIN_LEFT_MOTOR_IB, leftPwm);
  } else {
    // Stop Left Motor
    writePWM(PIN_LEFT_MOTOR_IA, 0);
    writePWM(PIN_LEFT_MOTOR_IB, 0);
  }

  // --- Right Motor Direction Control ---
  if (rightSpeed > 0) {
    // Drive Right Forward
    writePWM(PIN_RIGHT_MOTOR_IA, rightPwm);
    writePWM(PIN_RIGHT_MOTOR_IB, 0);
  } else if (rightSpeed < 0) {
    // Drive Right Reverse
    writePWM(PIN_RIGHT_MOTOR_IA, 0);
    writePWM(PIN_RIGHT_MOTOR_IB, rightPwm);
  } else {
    // Stop Right Motor
    writePWM(PIN_RIGHT_MOTOR_IA, 0);
    writePWM(PIN_RIGHT_MOTOR_IB, 0);
  }
}

/**
 * @brief Reads, buffers, and parses incoming Serial data.
 * 
 * Listens for commands like "M:left,right\n" and routes parsed speeds.
 */
void processSerialInput() {
  static String inputBuffer = ""; // Static buffer to preserve data across loops

  while (Serial.available() > 0) {
    char c = (char)Serial.read();
    
    // Check for packet terminator
    if (c == '\n' || c == '\r') {
      if (inputBuffer.length() > 0) {
        inputBuffer.trim(); // Strip extraneous whitespace
        
        // Ensure packet matches basic protocol: starts with 'M' or 'm' and has ':'
        if ((inputBuffer.startsWith("M") || inputBuffer.startsWith("m")) && inputBuffer.indexOf(':') != -1) {
          int colonIdx = inputBuffer.indexOf(':');
          String speedData = inputBuffer.substring(colonIdx + 1);
          int commaIdx = speedData.indexOf(',');
          
          if (commaIdx != -1) {
            String leftStr = speedData.substring(0, commaIdx);
            String rightStr = speedData.substring(commaIdx + 1);
            
            leftStr.trim();
            rightStr.trim();

            int leftSpeed = leftStr.toInt();
            int rightSpeed = rightStr.toInt();

            // Set motor speeds immediately
            setMotorSpeeds(leftSpeed, rightSpeed);
            
            // Refresh failsafe timestamp
            lastCommandTime = millis();
            if (failsafeTriggered) {
              failsafeTriggered = false;
              Serial.println("INFO: Communication restored. Failsafe inactive.");
            }
            
            // Acknowledge receipt back to the Raspberry Pi
            Serial.printf("ACK:%d,%d\n", leftSpeed, rightSpeed);
          } else {
            Serial.println("ERR: Malformed speed arguments. Missing comma separator.");
          }
        } else {
          Serial.printf("ERR: Unknown command prefix in string: '%s'\n", inputBuffer.c_str());
        }
        inputBuffer = ""; // Reset buffer after processing command packet
      }
    } else {
      // Append character to the processing buffer if length constraints allow
      if (inputBuffer.length() < 64) {
        inputBuffer += c;
      } else {
        // Prevent buffer overflows from noise
        inputBuffer = "";
        Serial.println("ERR: Serial receive buffer overflow.");
      }
    }
  }
}

/**
 * @brief Implements the timeout failsafe safety protocol.
 * 
 * Halts motors if no telemetry activity has occurred in FAILSAFE_TIMEOUT_MS.
 */
void handleFailsafe() {
  unsigned long now = millis();
  
  if (now - lastCommandTime > FAILSAFE_TIMEOUT_MS) {
    if (!failsafeTriggered) {
      // Stop both motors instantly for safety
      setMotorSpeeds(0, 0);
      failsafeTriggered = true;
      Serial.println("WARNING: Failsafe triggered! Serial communication lost. Motors stopped.");
    }
    // Constantly refresh command timestamp to prevent rollover overflow glitches, 
    // but keep failsafe flag active.
    lastCommandTime = now - (FAILSAFE_TIMEOUT_MS + 10);
  }
}

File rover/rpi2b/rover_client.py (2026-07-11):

"""
Stasis Forest Monitoring Rover - Raspberry Pi Client

This module runs on the Raspberry Pi (Rover Client) and establishes a WebSocket
connection with the host monitoring server. It receives navigation targets
and scanning requests, executing closed-loop PID turning, open-loop driving,
ultrasonic scanning, and sensor telemetry gathering.

Hardware Support:
- Direct DC Motor control via L911S H-Bridge connected directly to Pi GPIOs.
- ESP32-S3-delegated DC Motor control via UART/Serial interface (using SerialMotorDriver).
- Gyroscope yaw/imu sensing using MPU6050 over I2C.
- Compass heading sensing using HMC5883L/GY-271 over I2C.
- HC-SR04 Ultrasonic Distance Sensor for obstacle detection and scanning.
- SG90 servo motor for sweeping the ultrasonic sensor.
"""

from __future__ import annotations

import argparse
import base64
import json
import logging
import math
import os
import queue
import signal
import threading
import time
from dataclasses import dataclass, field, fields
from pathlib import Path
from typing import Any

import websocket

# Identifies the client device type to the server during WebSocket registration
ROVER_TYPE = "rover"

MODE_IDLE = "IDLE"
MODE_MANUAL = "MANUAL"
MODE_PATROL = "PATROL"
MODE_FOLLOW = "FOLLOW"
MODE_EMERGENCY_STOP = "EMERGENCY_STOP"
MODE_WAITING_DECISION = "IDLE_WAITING_DECISION"


@dataclass
class PinConfig:
    """
    GPIO Pin Allocations based on Broadcom (BCM) numbering on the 40-pin header.
    These are only used if direct Raspberry Pi GPIO hardware interfaces are enabled.
    """

    left_motor_forward: int = 5
    left_motor_reverse: int = 6
    right_motor_forward: int = 13
    right_motor_reverse: int = 19
    left_motor_enable: int | None = None
    right_motor_enable: int | None = None
    ultrasonic_trig: int = 23
    ultrasonic_echo: int = 24
    scanner_servo: int = 18


@dataclass
class MotionConfig:
    """
    Configuration parameters for movement calibration, PID constants, and timing timeouts.
    """

    turn_kp: float = 0.8  # Proportional gain for closed-loop PID turning
    turn_tolerance_deg: float = (
        5.0  # Acceptable angular error margin to declare a turn complete
    )
    turn_min_pwm: float = (
        35.0  # Minimum duty cycle to overcome static friction during turning
    )
    turn_max_pwm: float = (
        85.0  # Cap on motor speed duty cycle during high-error PID turns
    )
    drive_pwm: float = 70.0  # Default forward driving speed duty cycle
    drive_ms_per_cm: float = (
        50.0  # Open-loop calibration constant mapping drive duration to distance
    )
    turn_timeout_seconds: float = (
        12.0  # Timeout limit before aborting a closed-loop turn operation
    )
    telemetry_interval_seconds: float = (
        0.5  # Periodicity of sending status packets back to the dashboard
    )
    heartbeat_interval_seconds: float = 5.0  # Periodicity of keep-alive signals
    scan_step_deg: int = 30  # Angle step increment during ultrasonic sonar sweep
    scan_settle_seconds: float = (
        0.25  # Delay to let servo stabilize before firing ultrasound trigger
    )
    follow_base_pwm: float = 42.0
    follow_turn_pwm: float = 28.0
    follow_target_area_ratio: float = 0.16
    follow_deadband_ratio: float = 0.12
    follow_lost_timeout_seconds: float = 2.5
    follow_update_interval_seconds: float = 0.2


@dataclass
class SensorConfig:
    """
    Configuration for onboard I2C sensors (MPU6050 Gyro, HMC5883L Compass).
    """

    i2c_bus: int = 1
    mpu6050_address: int = 0x68
    hmc5883l_address: int = 0x1E
    compass_declination_deg: float = 0.0
    gyro_calibration_samples: int = 300
    gyro_deadband_deg_per_sec: float = 0.25


@dataclass
class HardwareConfig:
    """
    Switches to toggle physical hardware subsystems on/off, or enable serial communication delegation.
    """

    direct_motor_control: bool = (
        True  # Directly drive motor controller from Raspberry Pi GPIO pins
    )
    motor_driver: str = "l911s"  # Direct GPIO driver type: l911s or l298n
    esp32_serial_control: bool = (
        False  # Delegate L911S motor driving to ESP32-S3 over Serial
    )
    esp32_serial_port: str = "/dev/ttyUSB0"  # Serial port device node (e.g. COM3 on Win, /dev/ttyUSB0 on Linux)
    esp32_baudrate: int = 115200  # Baud rate matching ESP32 controller firmware
    i2c_enabled: bool = False  # Master toggle for I2C communication
    mpu6050_enabled: bool = False  # MPU6050 Inertial Measurement Unit toggle
    compass_enabled: bool = False  # GY-271 / HMC5883L Magnetometer toggle
    ultrasonic_enabled: bool = False  # HC-SR04 ultrasonic rangefinder toggle
    scanner_servo_enabled: bool = False  # SG90 sweep servo toggle
    require_heading_for_goto: bool = (
        False  # Reject navigation goals if no active IMU/Compass exists
    )
    open_loop_turn_degrees_per_second: float = (
        90.0  # Fallback calibration constant for non-IMU turns
    )
    obstacle_stop_distance_cm: float = (
        25.0  # Minimum distance threshold before emergency stopping
    )
    obstacle_check_interval_seconds: float = (
        0.1  # Polling rate of ultrasonic sensor during drive forward
    )


@dataclass
class CameraConfig:
    """
    USB webcam capture settings for frames sent from Raspberry Pi to the Windows server.
    """

    enabled: bool = True
    index: int = 0
    width: int = 640
    height: int = 480
    fps: int = 10
    jpeg_quality: int = 70
    upload_interval_seconds: float = 2.0
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

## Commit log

2026-07-04 Redesign docs site to match Mission Control Dashboard theme
    - Replace forest/nature color palette with dashboard's dark mission-control design system
    - Switch to Inter (body), Space Grotesk (headline), JetBrains Mono (mono) fonts
    - Use dashboard accent colors: cyan, green, amber, red, violet
    - Apply grid overlay background, rounded panels with gradient surfaces
    - Remove light-theme toggle — dark-only to match dashboard
    - Update SVG pipeline colors, HUD widget colors to match new palette
    - Add hero gradient with cyan accent glow
    - Maintain all interactive JS features (pipeline diagram, console, scroll story)
2026-07-04 New animated radar-scan logo GIF + sync brand identity across dashboard and docs
    - Replace static stasis-logo.png with creative animated GIF logo
    - Animated radar scan with pulsing rings, rotating scan line, glowing center, detection boxes, corner crosshairs
    - Docs nav logo now uses the animated GIF instead of PNG
    - Dashboard sidebar logo replaced Material Symbols icon with same animated GIF
    - Both pages now share identical animated brand mark
    - Bump brand-logo size to 44px for better visibility on both pages
    - Remove rotate hover effect on docs logo (unnecessary with animation)
2026-07-04 Theme all docs sub-pages to match dashboard — rewrite site.css + layout
    - Rewrite site.css with dashboard design tokens (black bg, grid overlay, cyan/green/amber accent palette, Inter + Space Grotesk + JetBrains Mono fonts)
    - Update Jekyll layout to use animated stasis-logo.gif instead of static stasis-mark.svg
    - Add gh-link style for GitHub nav button (matches dashboard's nav-action)
    - Remove old forest/moss color palette from all sub-pages
    - Update _config.yml description to remove forest reference
    - All sub-pages (README_ROVER_SYSTEM, VISION_PROVIDERS, etc.) now share the same theme as the dashboard
2026-07-09 docs: visual polish — OG metadata, favicon, animations, card icons, footer, back-to-top, HUD auto-demo
2026-07-09 docs: comprehensive mobile responsiveness — 5 breakpoints (1024/820/500/360px), bigger touch targets, no fixed heights, better stacking
2026-07-09 docs: creative mouse effects — cursor spotlight, 3D card tilt, magnetic buttons
2026-07-09 docs: dramatic visual effects — animated gradient border on hero, pulsing glow, shimmer subtitle, auto-start HUD demo
2026-07-09 docs: hero beauty pass — gradient shimmer heading, floating particles, glow line, removed tilt/shake/spotlight
2026-07-09 docs: Matrix rain hero — canvas digital rain, scanlines, green glow, removed particles
2026-07-09 docs: mobile Matrix rain — smaller fonts, lighter card opacity (72%), thinner blur
2026-07-10 feat: ultrasonic distance, route planner dashboard, patrol rewrite, L298N config
2026-07-11 Strip reasoning refs from docs site - Remove 'local AI reasoning' from meta description - Remove 'Reasoning: local qwen2.5-coder' code block from pipeline steps
    Detection fixes: normalize_detection handles both box (dict) and bbox (list)
    format; expanded YOLOE classes to person, animal, dog, cat, bird, bear, toy
    at 15% confidence.
    Route fix: _execute_route uses direct set_motors with timed duration instead
    of handle_goto (eliminates open-loop turn curving).
    Camera: del cap on unopened cameras, 5s retry backoff, default backend.
    L298N: direction-pin PWM for speed control (drive_pwm=45 respected).
    Patrol: periodic turns, ignore follow commands during patrol.
    Config: config.lowbandwidth.js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
    [rover_client.py]
